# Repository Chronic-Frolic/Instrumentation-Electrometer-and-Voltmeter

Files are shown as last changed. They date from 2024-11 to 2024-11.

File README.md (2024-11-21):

# Instrumentation Electrometer and Voltmeter
Instrumentation Electrometer and Voltmeter for Proyecto Avanzado I, Engineering Physics undergraduate course, EAFIT University.

## Referencias
[1] PHYWE Systeme GmbH & Co. KG, Universal Measuring Amplifier: Operating Instructions, Göttingen, Alemania. [En línea]. Disponible en: www.phywe.com. Acceso: 20 de noviembre de 2024.

[2] PHYWE Systeme GmbH & Co. KG, Photocell with Housing: Operating Instructions, Göttingen, Alemania. [En línea]. Disponible en: www.phywe.com. Acceso: 20 de noviembre de 2024.

[3] PHYWE Systeme GmbH & Co. KG, Dielectric Constant of Different Materials: Operating Instructions, Göttingen, Alemania. [En línea]. Disponible en: www.phywe.com. Acceso: 20 de noviembre de 2024.

[4] PHYWE Systeme GmbH & Co. KG, Diffraction through a Slit and Heisenberg’s Uncertainty Principle: Operating Instructions, Göttingen, Alemania. [En línea]. Disponible en: www.phywe.com. Acceso: 20 de noviembre de 2024.

[5] PHYWE Systeme GmbH & Co. KG, Planck’s “Quantum of Action” from the Photoelectric Effect: Laboratory Experiment, Göttingen, Alemania. [En línea]. Disponible en: www.phywe.com. Acceso: 20 de noviembre de 2024.

[6] Microchip Technology Inc., MCP6001/1R/1U/2/4 - 1 MHz, Low-Power Op Amp: Datasheet, documento DS20001733L, versión actualizada 2020. [En línea]. Disponible en: www.microchip.com. Acceso: 20 de noviembre de 2024.

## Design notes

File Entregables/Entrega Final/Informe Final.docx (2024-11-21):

# Desarrollo de Voltímetro de Instrumentación y Electrómetro de Instrumentación para su Uso en Laboratorios de Física

S. Jiménez* y C. A. Trujillo†

Escuela de Ciencias Aplicadas e Ingeniería, Universidad EAFIT.

Carrera 49 #7 sur 50, Medellín, Colombia.

*sjimenezh1@eafit.edu.co

†catrujilla@eafit.edu.co

# Resumen

Se presenta el desarrollo de un voltímetro y un electrómetro de instrumentación, diseñados como alternativas económicas al amplificador universal de PHYWE para laboratorios de física. El voltímetro fue probado con éxito en experimentos para confirmar el Principio de Incertidumbre de Heisenberg, mientras que el electrómetro, en su etapa final de diseño, está optimizado para determinar la constante de Planck y constantes dieléctricas. Ambos instrumentos destacan por su modularidad, reparabilidad y adecuación educativa. Este documento describe el proceso iterativo de desarrollo, la validación experimental y la comparación con el amplificador de PHYWE, resaltando las mejoras introducidas.

Palabras Clave: Metrología, Electromagnetismo, Física Moderna, Principio de Incertidumbre de Heisenberg, Constante de Planck, Constante Dieléctrica, Voltímetro, Electrómetro.

# Abstract

We present the development of an instrumentation voltmeter and electrometer designed as cost-effective alternatives to the PHYWE universal measuring amplifier for use in physics laboratories. The voltmeter was successfully tested in experiments confirming Heisenberg's Uncertainty Principle, while the electrometer, in its final design stage, is optimized for determining Planck's constant and dielectric constants. Both instruments prioritize modularity, repairability, and educational suitability. This document details the iterative development process, experimental validation, and comparison with the PHYWE amplifier, emphasizing the improvements introduced by these instruments.

Keywords: Metrology, Electromagnetism, Modern Physics, Heisenberg's Uncertainty Principle, Planck's Constant, Dielectric Constant, Voltmeter, Electrometer.

# Introducción

El desarrollo de instrumentos de medición asequibles y funcionales es crucial para mejorar la experiencia educativa en laboratorios de física. Este proyecto aborda las limitaciones del amplificador universal de medición PHYWE, cuyo alto costo, configuración compleja y falta de una pantalla integrada dificultan su uso en entornos académicos. Se diseñaron y construyeron un voltímetro y un electrómetro de instrumentación, enfocados en la simplicidad de uso, reparabilidad y costo reducido, optimizando su integración en experimentos como la confirmación del Principio de Incertidumbre de Heisenberg, la determinación de la constante de Planck y determinación de constantes dieléctricas.

El diseño se centró en instrumentos compactos y específicos para cada experimento, eliminando configuraciones previas y mejorando la ergonomía en el laboratorio. Estos dispositivos buscan no solo igualar las capacidades del equipo comercial, sino también ofrecer una alternativa sostenible y adaptable a largo plazo.

Este artículo detalla la metodología de diseño y fabricación de los instrumentos, presenta los resultados obtenidos y discute las mejoras proyectadas para maximizar su desempeño en aplicaciones futuras.

# Metodología

El desarrollo del voltímetro y electrómetro de instrumentación se llevó a cabo mediante un enfoque iterativo dividido en etapas claras: diseño electrónico, diseño y fabricación de la carcasa, ensamblaje de componentes y pruebas funcionales. Este proceso permitió realizar cuatro prototipos para el voltímetro y dos para el electrómetro, asegurando un diseño optimizado y funcional para ambos instrumentos. Estas herramientas, diseñadas para experimentos de física moderna y electromagnetismo, se enfocaron en la precisión, modularidad y reparabilidad.

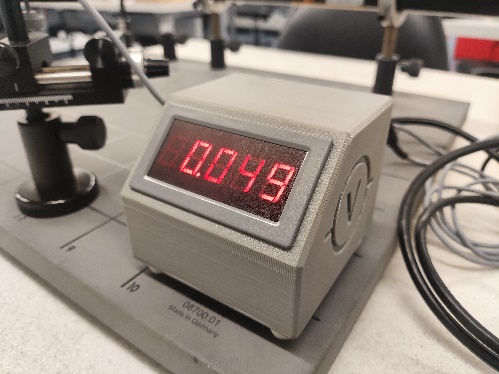
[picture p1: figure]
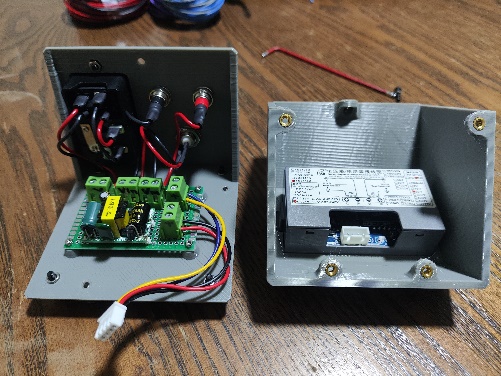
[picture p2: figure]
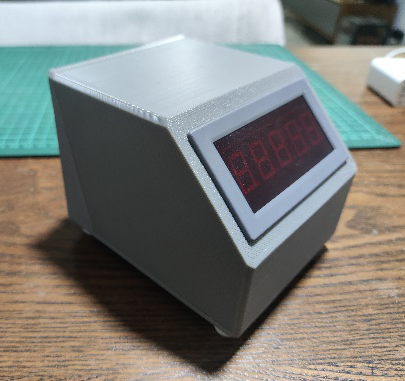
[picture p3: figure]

(a) (b) (c)

Figura 2: Diferentes iteraciones del voltímetro (a) Segundo prototipo (b) Tercer prototipo (detalle interno) (c) Cuarto prototipo

## Diseño Electrónico

Ambos instrumentos comparten componentes clave, incluidos el módulo voltímetro-pantalla YB5145B, el conector C13 con fusible y switch, y bloques terminales que refuerzan la modularidad. El módulo voltímetro-pantalla fue elegido por su precisión de ±1 mV, su retroiluminación roja y sus dígitos grandes, ideales para condiciones de baja iluminación, como las requeridas en los experimentos de física moderna.

El circuito del electrómetro utiliza un amplificador operacional MCP6001 en configuración de buffer de ganancia unitaria, seleccionado por su corriente de polarización de entrada extremadamente baja (1 pA), lo que permite que la resistencia general del circuito sea determinada por la alta resistencia entre los pines del circuito. Para mejorar su resistencia frente a errores operativos, el diseño final incluye un resistor de protección que limita la corriente de salida en condición de polarización inversa, aunque no se implementó protección contra sobrevoltaje debido a las corrientes de fuga asociadas a los diodos necesarios, que podrían comprometer las mediciones de alta precisión asociadas a cargas capacitivas.

Durante el desarrollo, el electrómetro experimentó un fallo crítico causado por un corto en la fuente de alimentación de 5 V, lo que dañó el amplificador operacional. Este problema será corregido en la versión final mediante el uso de un socket para facilitar el reemplazo del MCP6001 y garantizar la reparabilidad a largo plazo.

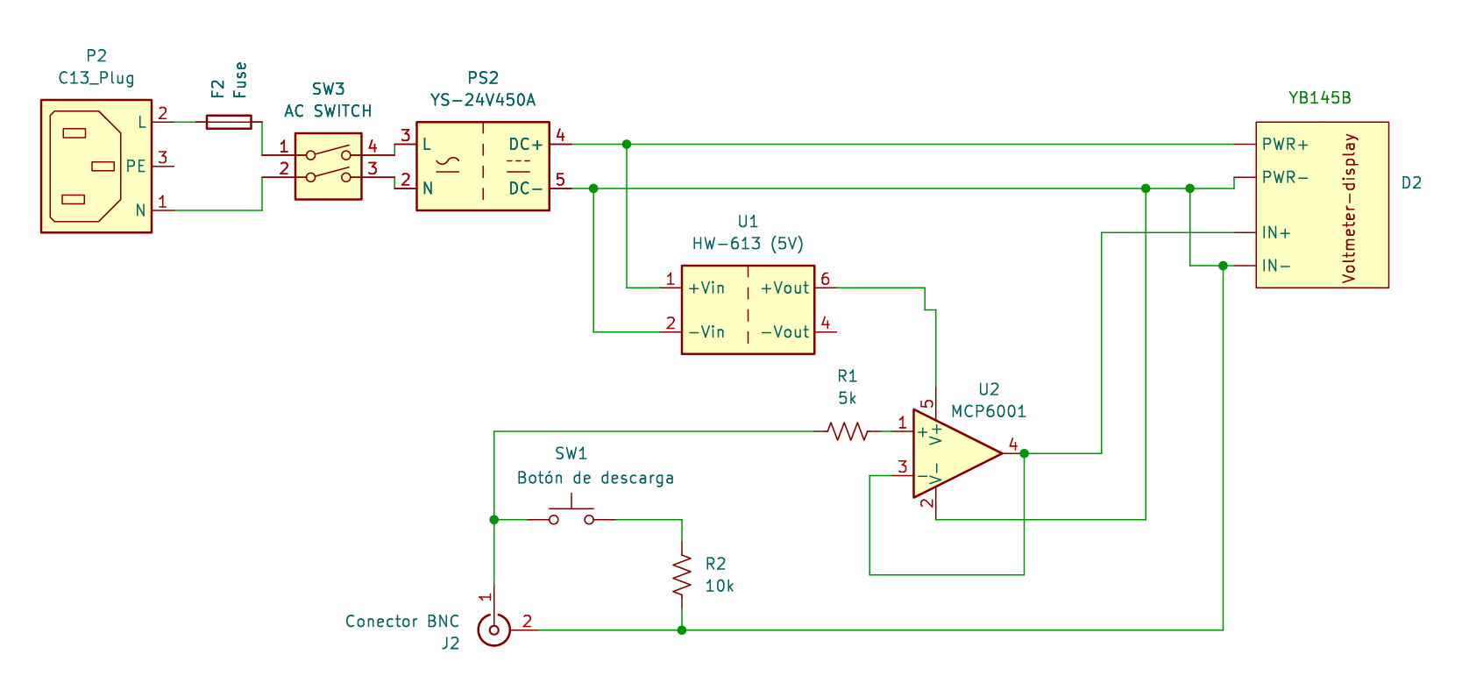
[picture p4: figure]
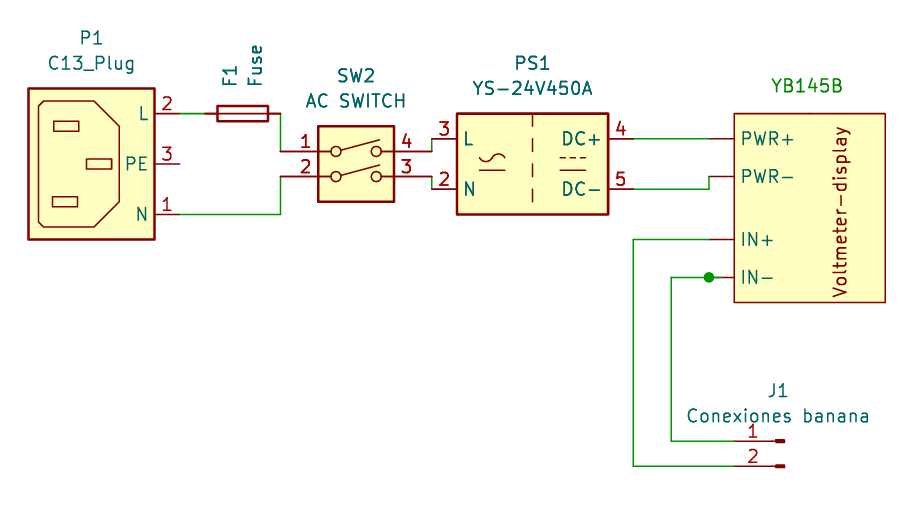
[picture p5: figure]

(a) (b)

Figura 1: Diagramas de conexiónes finales (a) Electrómetro (b) Voltímetro

## Diseño y Fabricación de la Carcasa

Las carcasas de ambos instrumentos se diseñaron en Autodesk Fusion 360 y se fabricaron en PETG utilizando impresión 3D con una Creality CR-10 modificada. El diseño priorizó la modularidad, y la facilidad de fabricación y mantenimiento, incorporando insertos roscados para permitir un desmontaje sencillo y ajustes futuros. Las carcasas comparten dimensiones compactas y presentan una inclinación de 45° en la pantalla, mejorando la ergonomía.

## Pruebas y Validación

La validación de los instrumentos se realizó integrándolos en los montajes experimentales correspondientes a dos aplicaciones clave: la confirmación del Principio de Incertidumbre de Heisenberg y la determinación de la constante de Planck.

En el primer experimento, un láser He-Ne fue dirigido hacia una rendija simple, generando un patrón de difracción. Una fotocélula, montada en un tornillo micrométrico, capturó la luz difractada. El voltímetro midió el voltaje de salida de la fotocélula en posiciones específicas, permitiendo identificar el máximo central y el primer mínimo, necesarios para calcular los ángulos de difracción.

Para el segundo experimento, una lámpara de vapor de mercurio proporcionó un espectro de emisión que fue separado en longitudes de onda específicas mediante una rejilla de difracción de 600 líneas/mm. Estas longitudes de onda incidieron sobre una fotocélula de vacío, generando un voltaje proporcional a la frecuencia de la luz incidente. El electrómetro midió este voltaje en condiciones de alta impedancia, garantizando que las características del circuito no afectaran las mediciones.

Ambos montajes aseguraron un entorno experimental adecuado para evaluar el desempeño de los instrumentos en contextos de física moderna, proporcionando las bases necesarias para los análisis posteriores.

## Enfoque en Modularidad y Reparabilidad

El diseño iterativo enfatizó la modularidad y reparabilidad como principios fundamentales. Los bloques terminales y el uso compartido del módulo voltímetro-pantalla simplifican el ensamblaje y permiten futuras reparaciones o ajustes según las necesidades. Este enfoque garantiza la sostenibilidad y adaptabilidad de los instrumentos, asegurando su utilidad a largo plazo en entornos de laboratorio.

_______________________

Este enfoque metodológico permitió la construcción de instrumentos específicos, precisos y funcionales, sentando las bases para los resultados experimentales que se presentan en la siguiente sección.

# Resultados

## Voltímetro

El voltímetro se utilizó en el experimento para confirmar el Principio de Incertidumbre de Heisenberg, midiendo los voltajes generados por una fotocélula en puntos clave del patrón de difracción. Los datos registrados permitieron calcular una relación de 2.0038, con el valor esperado siendo 1. Esta discrepancia se atribuye a un error en la ecuación proporcionada en la guía de laboratorio, no al desempeño del instrumento.

El voltímetro mostró una precisión de ±1 mV, equivalente al modo de baja deriva del amplificador PHYWE. Su integración directa en el montaje experimental simplificó la configuración, haciendo posible realizar las mediciones necesarias de forma compacta y eficiente.

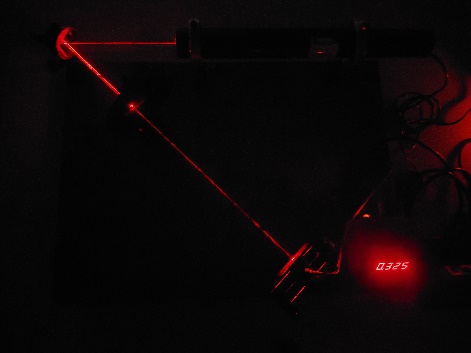
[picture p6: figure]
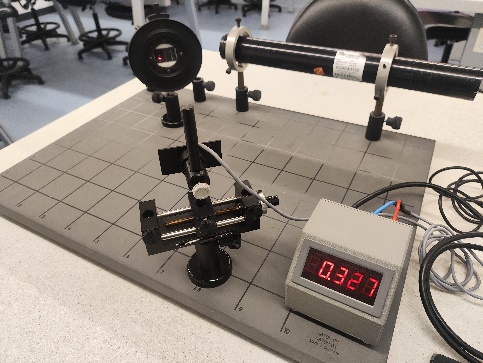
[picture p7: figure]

(a) (b)

Figura 3. Voltímetro (a) Desempeño en las condiciones experimentales (b) Integración al laboratorio

## Electrómetro

El electrómetro, aún en fase de ajustes finales, está diseñado para experimentos de determinación de la constante de Planck y medición de constantes dieléctricas. Su configuración incluye un rango de entrada de 0-5 V, adecuado para los voltajes esperados en estos experimentos, típicamente entre 0 y 2 V. La alta resistencia de entrada (10^12 Ω) asegura mediciones precisas minimizando pérdidas de carga, cumpliendo con los requisitos de los montajes experimentales.

El diseño inicial presentó un fallo crítico causado por un corto circuito en la fuente de alimentación de 5 V, lo que dañó el amplificador MCP6001. Este problema fue resuelto en el diseño final, que incorpora un socket para facilitar el reemplazo del amplificador y un resistor de protección que limita la corriente en caso de uso indebido. Estas mejoras refuerzan la durabilidad y la capacidad de reparación del electrómetro.

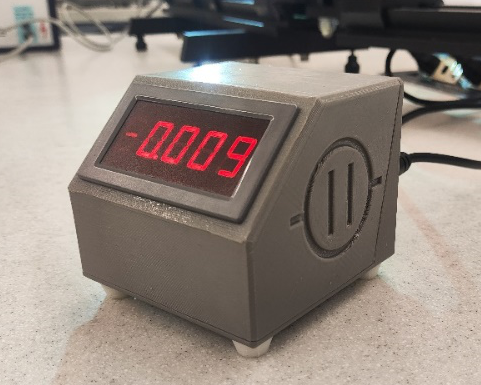
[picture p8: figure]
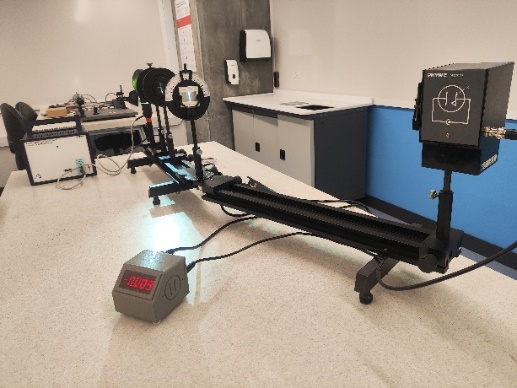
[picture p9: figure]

(a) (b)

Figura 4: Electrómetro (a) Detalle del primer prototipo (b) Integración con el experimento de determinación de la constante de Planck

## Comparación Cuantitativa con el Amplificador PHYWE

Característica | Voltímetro/Electrómetro | Amplificador PHYWE
Resolución (Voltímetro) | ±1 mV | ±1 mV
Resolución (Electrómetro) | ±1 mV | ±10 mV
Resistencia de entrada (Electrómetro) | 10^12 Ω | 10^13 Ω
Rango de voltaje (Electrómetro) | 0-5 V | ±10 V

Tabla 1: Comparativa cualitativa entre instrumentos desarrollados y el Amplificador Universal de Medida de PHYWE

Ambos instrumentos cumplen con los requisitos de los experimentos y presentan ventajas clave en términos de precisión y adaptabilidad. El voltímetro mostró un desempeño comparable al del amplificador PHYWE en el modo de baja deriva, mientras que el electrómetro, una vez finalizado, ofrecerá mayor flexibilidad y facilidad de uso en experimentos de alta impedancia.

# Conclusiones

El desarrollo del voltímetro y electrómetro de instrumentación representa un avance significativo en la implementación de herramientas asequibles, reparables y funcionales para laboratorios de física. Estos instrumentos no solo igualan, sino que en varios aspectos superan las capacidades del amplificador universal PHYWE, ofreciendo una solución práctica y sostenible para los experimentos de física moderna y electromagnetismo.

El voltímetro fue validado con éxito en el experimento del Principio de Incertidumbre de Heisenberg, demostrando un rendimiento equivalente al equipo comercial en precisión y superándolo en ergonomía y facilidad de uso. Su diseño compacto, pantalla integrada y capacidad para operar de manera autónoma mejoraron la experiencia experimental y optimizaron el espacio en el laboratorio.

Aunque el electrómetro no estuvo completamente funcional durante la etapa inicial, su diseño ha sido verificado como sólido y se están implementando ajustes finales. Una vez completadas estas modificaciones, permitirá realizar experimentos como la determinación de la constante de Planck y la medición de constantes dieléctricas con mayor precisión y confiabilidad que el equipo comercial, cuyo modo electrómetro está actualmente inoperativo.

Más allá de los logros técnicos, este proyecto tiene un impacto significativo en el contexto educativo. Los instrumentos desarrollados reducen los costos de equipamiento, democratizan el acceso a herramientas avanzadas y enriquecen la experiencia práctica de los estudiantes al ofrecer dispositivos diseñados para su facilidad de uso y sostenibilidad. Este enfoque no solo mejora la formación académica, sino que también sienta un precedente para futuros desarrollos en tecnología educativa.

El proyecto concluye con una base sólida para la implementación de estos instrumentos en los laboratorios de Ingeniería Física, marcando un paso hacia la modernización y optimización de las prácticas experimentales. Las pruebas finales del electrómetro están programadas para completarse con el experimento de determinación de h, lo que consolidará su utilidad en aplicaciones clave.

# Agradecimientos

Agradezco profundamente a Carlos Alejandro Trujillo por su invaluable guía a lo largo del desarrollo de este proyecto, brindando orientación clave en cada etapa. También extiendo mi gratitud a Álvaro Andrés Velásquez por su aporte en la verificación del circuito del electrómetro, cuya experiencia en electrónica analógica fue fundamental para garantizar la solidez técnica del electrómetro. Asimismo, agradezco al Centro de Laboratorios (CLAB) de la Universidad EAFIT por su apoyo financiero, que permitió la adquisición de los materiales y componentes necesarios para la construcción de los instrumentos.

# Referencias

[1] PHYWE Systeme GmbH & Co. KG, Universal Measuring Amplifier: Operating Instructions, Göttingen, Alemania. [En línea]. Disponible en: www.phywe.com. Acceso: 20 de noviembre de 2024.

[2] PHYWE Systeme GmbH & Co. KG, Photocell with Housing: Operating Instructions, Göttingen, Alemania. [En línea]. Disponible en: www.phywe.com. Acceso: 20 de noviembre de 2024.

[3] PHYWE Systeme GmbH & Co. KG, Dielectric Constant of Different Materials: Operating Instructions, Göttingen, Alemania. [En línea]. Disponible en: www.phywe.com. Acceso: 20 de noviembre de 2024.

[4] PHYWE Systeme GmbH & Co. KG, Diffraction through a Slit and Heisenberg’s Uncertainty Principle: Operating Instructions, Göttingen, Alemania. [En línea]. Disponible en: www.phywe.com. Acceso: 20 de noviembre de 2024.

[5] PHYWE Systeme GmbH & Co. KG, Planck’s “Quantum of Action” from the Photoelectric Effect: Laboratory Experiment, Göttingen, Alemania. [En línea]. Disponible en: www.phywe.com. Acceso: 20 de noviembre de 2024.

[6] Microchip Technology Inc., MCP6001/1R/1U/2/4 - 1 MHz, Low-Power Op Amp: Datasheet, documento DS20001733L, versión actualizada 2020. [En línea]. Disponible en: www.microchip.com. Acceso: 20 de noviembre de 2024.

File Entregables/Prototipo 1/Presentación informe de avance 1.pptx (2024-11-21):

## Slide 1

## Primer informe de avance

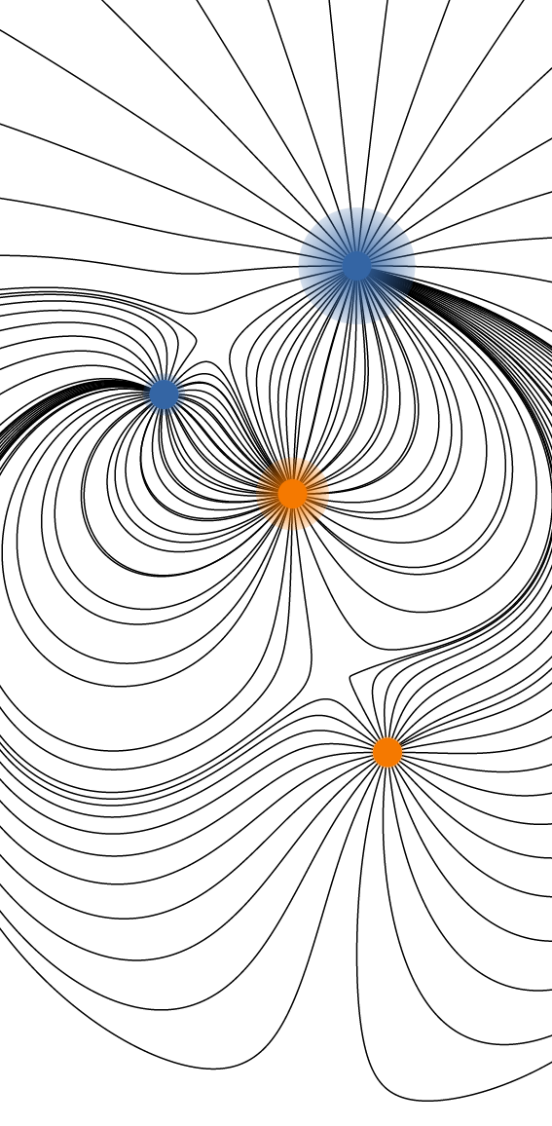
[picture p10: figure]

- Desarrollo de medidor de voltaje de instrumentación para su uso en laboratorios de física

## Índice

- Resultados

Avance del cronograma

Estrategias de mitigación

Conclusiones

Bibliografía

## Resultados

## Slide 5

Revisión teórica

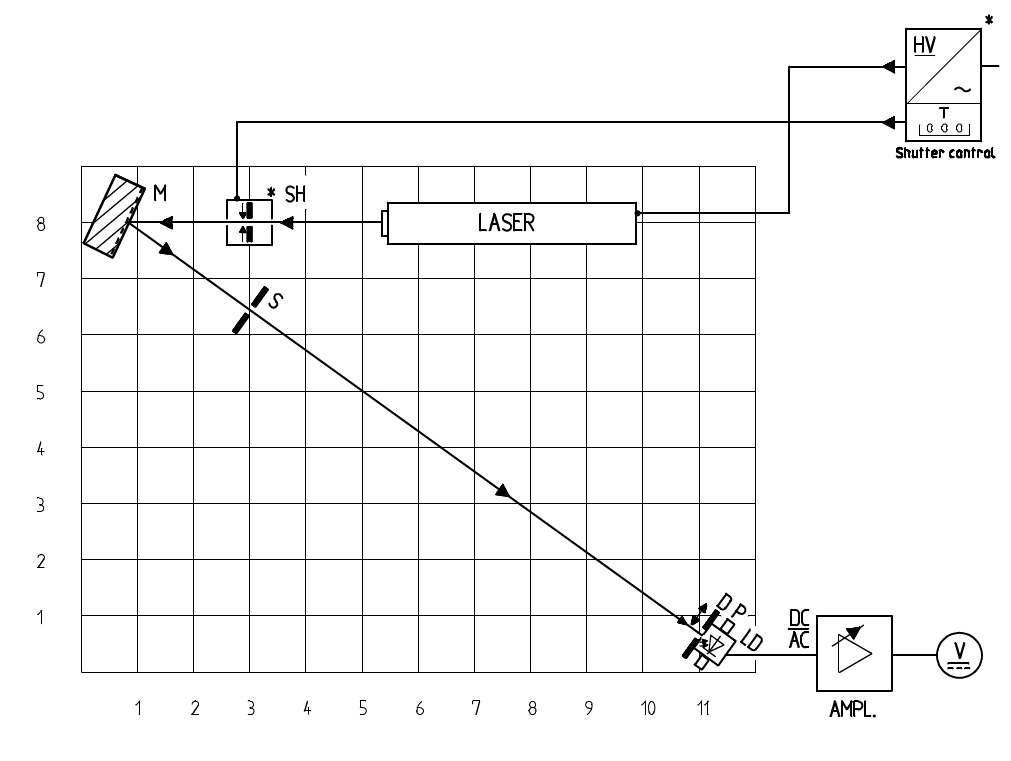
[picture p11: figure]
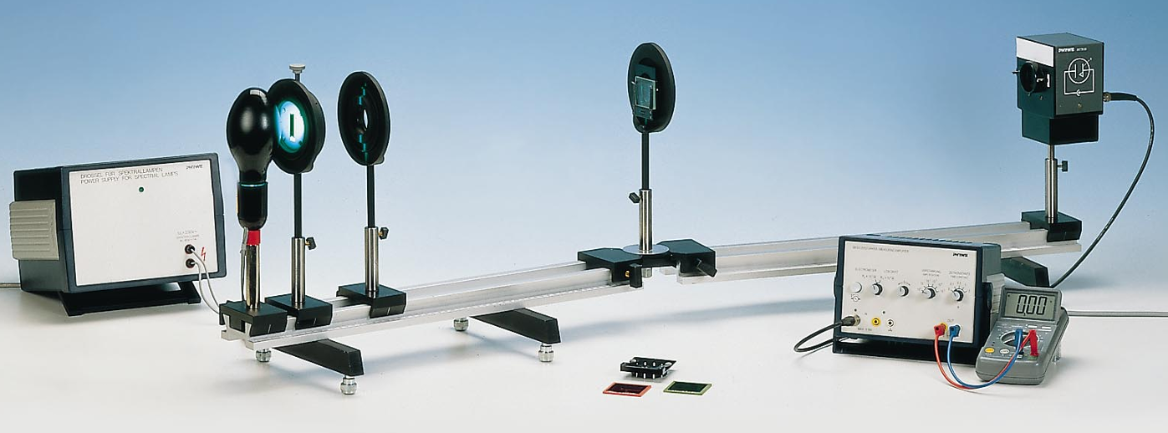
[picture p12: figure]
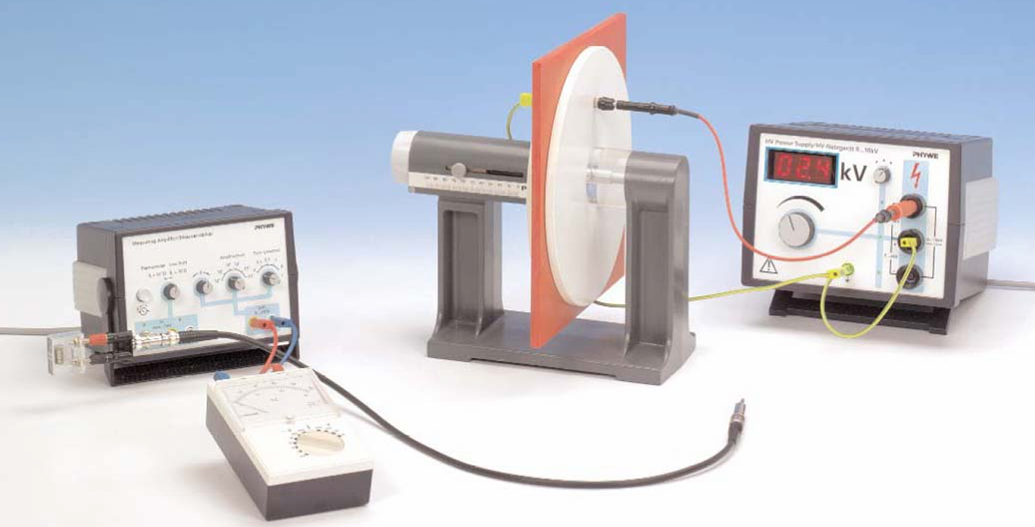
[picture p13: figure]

Tomado de [2]

Tomado de [1]

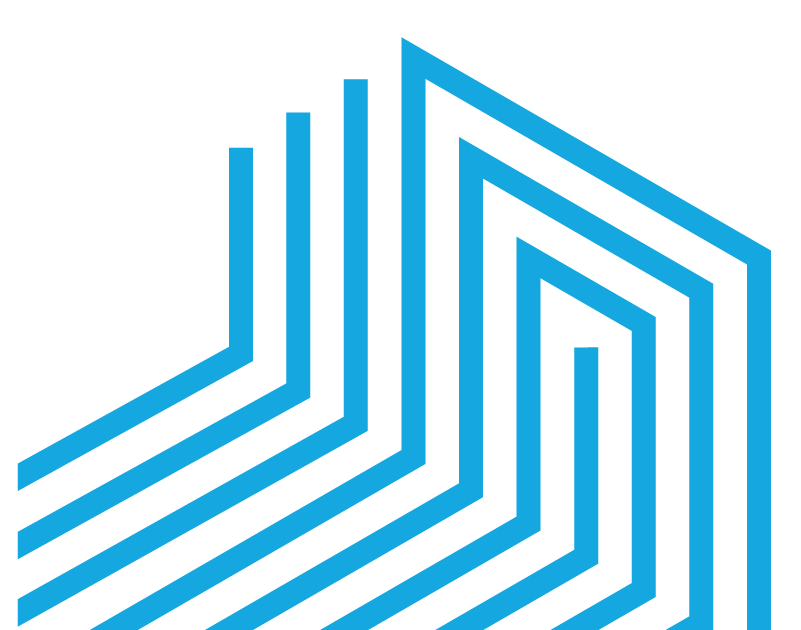
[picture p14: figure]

Tomado de [3]

## Prototipo 1

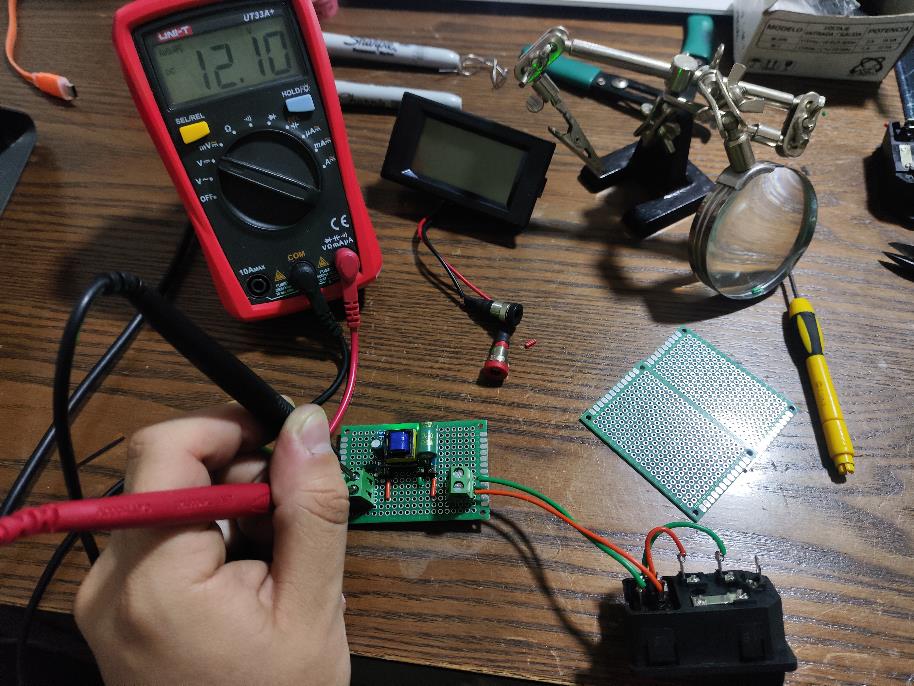
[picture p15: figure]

Elaboración propia

- Caracterización de la fuente de poder

## Prototipo 1

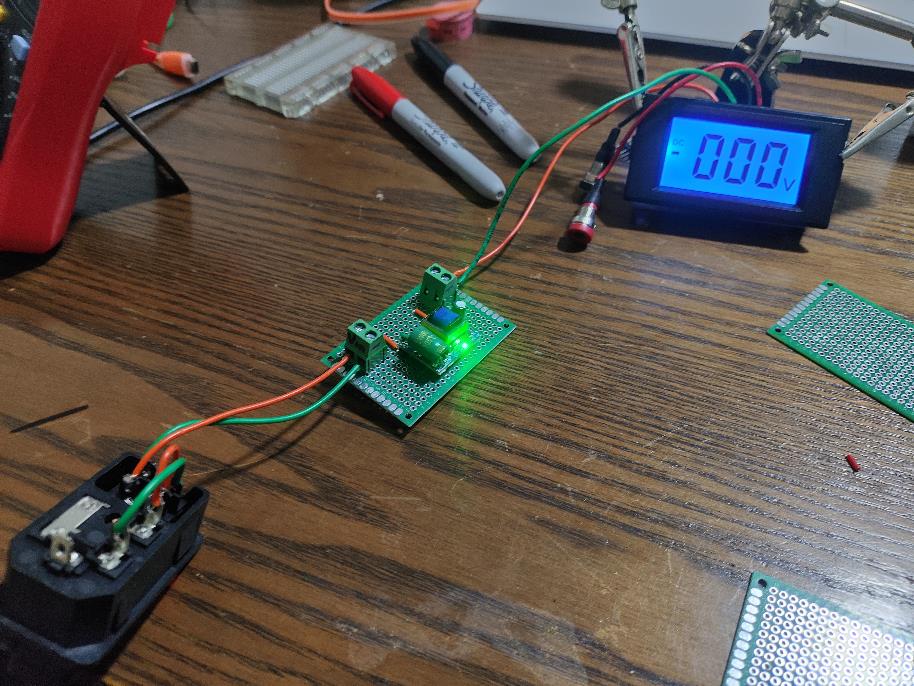
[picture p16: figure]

Elaboración propia

- Verificación del circuito final

## Prototipo 1

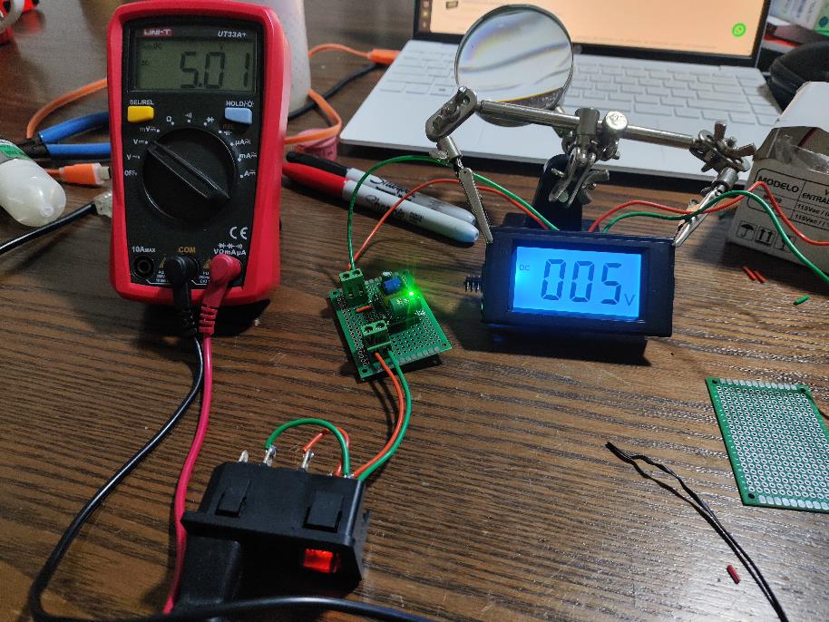
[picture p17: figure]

Elaboración propia

- Precisión y exactitud de la medida

## Prototipo 1

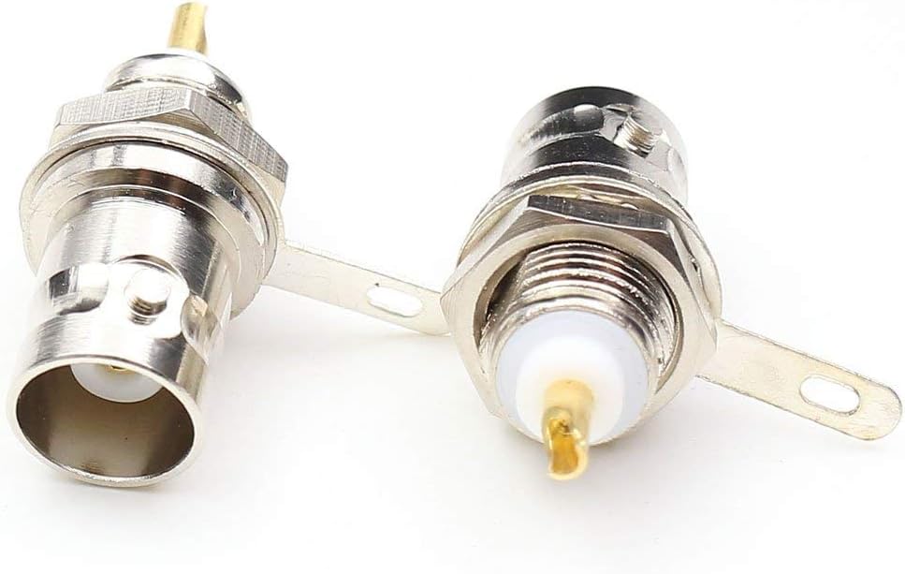
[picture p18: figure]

Tomado de [4]

- Consecusión de partes fundamentales

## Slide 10

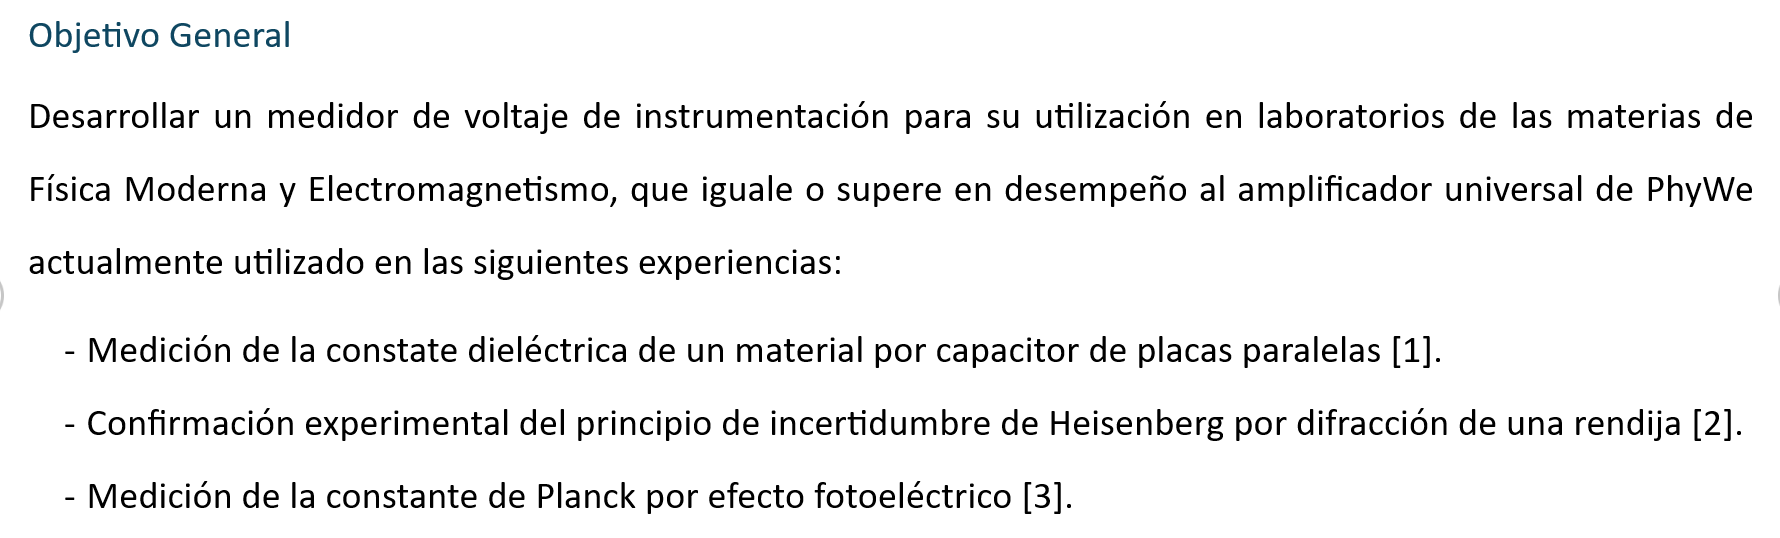
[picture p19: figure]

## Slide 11

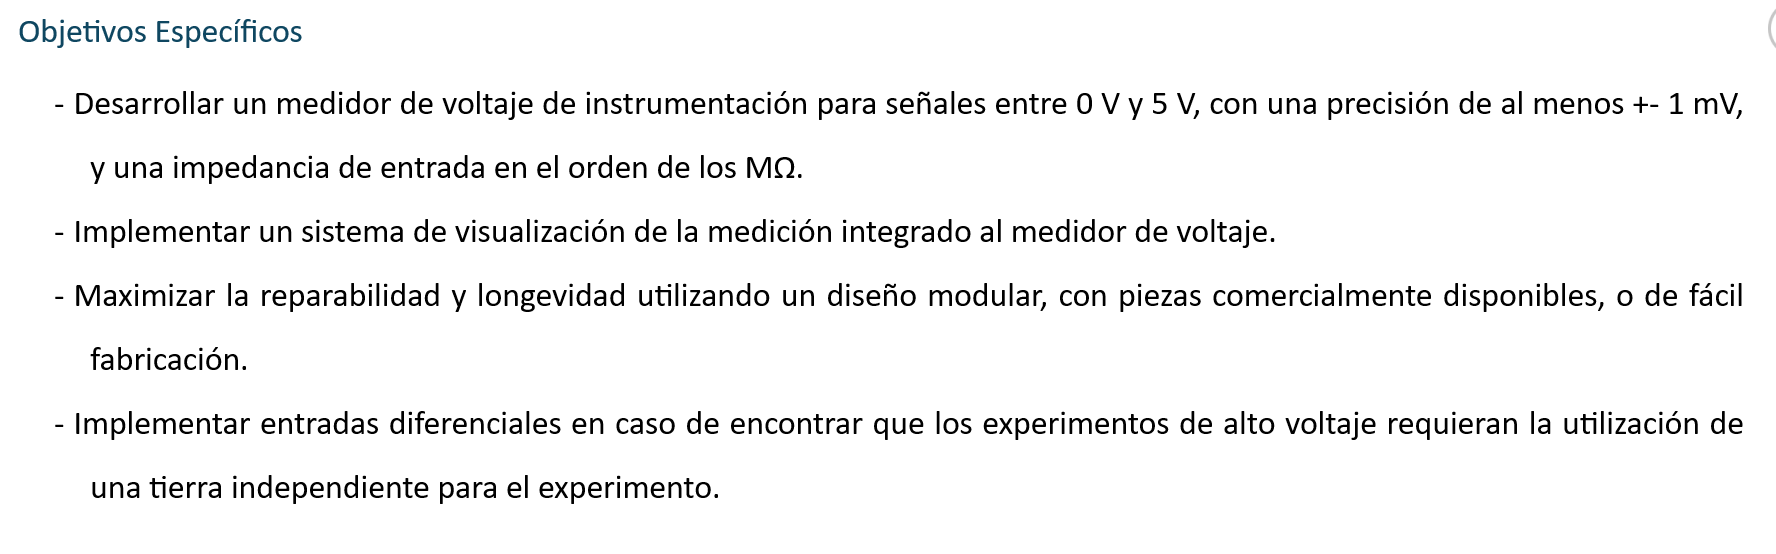
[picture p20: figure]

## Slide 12

Avance del cronograma

Etapa | Diseño electrónico | Diseño Carcasa | Elaboración electrónica | Elaboración carcasa | Pruebas de funcionamiento
Fundamentación (Definición del proyecto e investigación inicial) | Semanas 2 – 4
Prototipo 1 | Semana 5 | Semana 6 | Semana 7 | Semana 7 | Semana 8
Prototipo 2 | Semana 8 | Semana 9 | Semana 9 | Semana 10 | Semana 10
Medidor final | Semana 10 | Semana 11 | Semana 12 | Semana 13 | Semana 13
Documentación y reporte de resultados | Semanas 14 - 16

## Mitigación

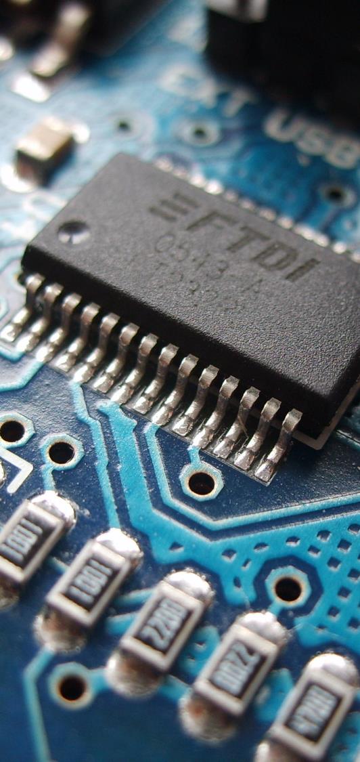
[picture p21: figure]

- Se implementarán las siguientes estrategias:

- Distribuidores: Amazon y Aliexpress

- Se fabricará un cable BNC a conector banana para hacer compatible el prototipo 1

- Se usará el prototipo 1 para hacer pruebas de funcionamiento

- Importación de partes fundamentales

- Estrategias de

- Adaptación de experimentos

- Pruebas preeliminares

## Partes en importación

Tomado de [4]

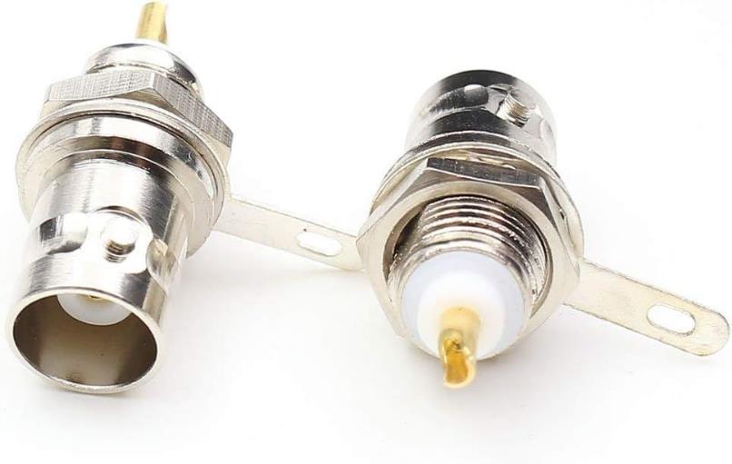
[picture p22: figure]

- Conectores BNC compatibles con equipos PHYWE

## Partes en importación

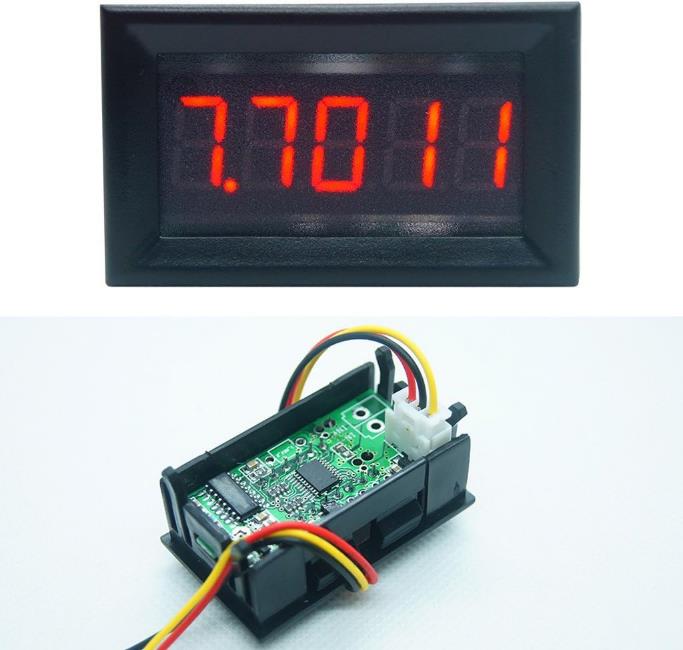
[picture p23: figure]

- Opción 1: Módulo voltímetro de alta precision con funcionalidad tare

Tomado de [5]

## Partes en importación

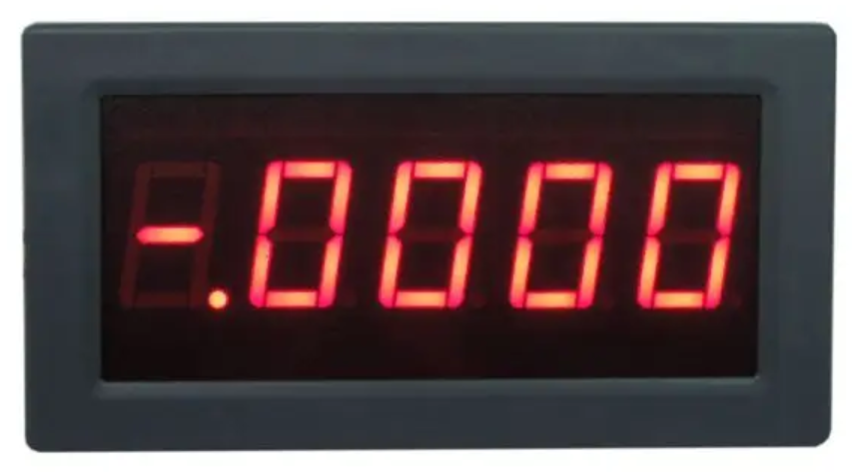
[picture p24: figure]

- Opción 2: Módulo voltímetro de aislamiento de alta precision

Tomado de [6]

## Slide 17

Conclusiones

## Bibliografía

[1] PHYWE Systeme GmbH & Co., "Dielectric constant of different materials," Göttingen.
[2] PHYWE Systeme GmbH & Co., "Diffraction through a slit and Heisenberg's uncertainty principle," Göttingen.
[3] PHYWE Systeme GmbH & Co., "Plank's "quantum of action" from the photoelectric effect (line separation by difraction),“ Göttingen.
[4] Amazon.com, "BNC Chassis Panel Mount Socket Female Jack Solder Type Connectors Adapter 6-Pack," [Online]. Available: https://www.amazon.com/gp/product/B07FB39S1L/ref=ox_sc_act_title_3?smid=A10PG8DP5LW0Q1&psc=1. [Accessed 2024]
[5] Amazon.com, "Digital Voltmeter DC Voltage Display 0-33.000V (0-33V) 5-Digits Bit High Precision Voltage Meter," [Online]. [Accessed 2024].
[6] Aliexpress.com, "YB5145BI DC Isolation Voltmeter 4 1/2 LED Digital Voltage Meter 5 Bits," [Online]. [Accessed 2024].

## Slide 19

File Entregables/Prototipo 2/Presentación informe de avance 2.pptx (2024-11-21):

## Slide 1

## Primer informe de avance


- Desarrollo de medidor de voltaje de instrumentación para su uso en laboratorios de física
- Estudiante: Sebastián Jiménez Henao
- Tutor: Carlos Alejandro Trujillo Anaya
- 25-10-2025

## Índice

- Resultados

Avance del cronograma

Conclusiones

Bibliografía

## Resultados

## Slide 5

Revisión teórica


Tomado de [1]


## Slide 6

Revisión teórica


Tomado de [2]

## Prototipo 2


Elaboración propia

- Modelado de carcasa impresa


## Prototipo 2


Elaboración propia

- Verificación de funcionamiento

## Prototipo 3


Elaboración propia

- Miniaturización y refinamiento final

## Prototipo 3


Elaboración propia

- Miniaturización y refinamiento final

## Prototipo 3


Elaboración propia

- Verificación de funcionamiento

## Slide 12

Objetivo general

Desarrollar un medidor de voltaje de instrumentación comparable en desempeño al amplificador universal Phywe actualmente en uso en las siguientes experiencias de Ingeniería Física de la Universidad EAFIT:
- Confirmación experimental del principio de incertidumbre de Heisenberg por difracción de una rendija [1].
- Medición de la constante de Planck por efecto fotoeléctrico [2].

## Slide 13

Objetivos específicos

- Desarrollar un medidor de voltaje de instrumentación para señales entre 0 V y 5 V, con una precisión de al menos +- 1 mV, y una impedancia de entrada en el orden de los MΩ.
- Implementar un sistema de visualización de la medición integrado al medidor de voltaje.
- Maximizar la reparabilidad y longevidad utilizando un diseño modular, con piezas comercialmente disponibles, o de fácil fabricación.

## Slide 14

Avance del cronograma

Etapa\Semana | 1 | 2 | 3 | 4 | 5 | 6 | 7 | 8 | 9 | 10 | 11 | 12 | 13 | 14 | 15 | 16
Fundamentación
Prototipo 1
Prototipo 2
Medidor final
Documentación y reporte de resultados

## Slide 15

Conclusiones

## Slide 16

Conclusiones

- Se cumplieron los objetivos específicos, logrando un medidor de voltaje pequeño, funcional y reparable.
- Quedan restando las pruebas de funcionamiento, pendiente de coordinación con el CLAB para las mismas.
- Se cumple la pregunta de investigación, demostrando la creación de un medidor de voltaje apto las experiencias previamente mencionadas de la materia de Física Moderna de la carrera de Ingeniería Física

## Bibliografía

[1] PHYWE Systeme GmbH & Co., "Diffraction through a slit and Heisenberg's uncertainty principle," Göttingen.
[2] PHYWE Systeme GmbH & Co., "Plank's "quantum of action" from the photoelectric effect (line separation by difraction),“ Göttingen.
[3] Amazon.com, "BNC Chassis Panel Mount Socket Female Jack Solder Type Connectors Adapter 6-Pack," [Online]. Available: https://www.amazon.com/gp/product/B07FB39S1L/ref=ox_sc_act_title_3?smid=A10PG8DP5LW0Q1&psc=1. [Accessed 2024]
[4] Amazon.com, "Digital Voltmeter DC Voltage Display 0-33.000V (0-33V) 5-Digits Bit High Precision Voltage Meter," [Online]. [Accessed 2024].
[5] Aliexpress.com, "YB5145BI DC Isolation Voltmeter 4 1/2 LED Digital Voltage Meter 5 Bits," [Online]. [Accessed 2024].

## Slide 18

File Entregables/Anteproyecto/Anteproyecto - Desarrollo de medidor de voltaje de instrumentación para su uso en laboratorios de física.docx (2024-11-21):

# Desarrollo de medidor de voltaje de instrumentación para su uso en laboratorios de física

Estudiante:

Sebastián Jiménez Henao (sjimenezh1@eafit.edu)

Tutor del proyecto:

Carlos Alejandro Trujillo Anaya (catrujilla@eafit.edu.co)

Profesora del curso:

Elena Montilla Rosero (emontill@eafit.edu.co)

Universidad EAFIT

Escuela de Ciencias Aplicadas e Ingeniería

Pregrado de Ingeniería Física

Proyecto Avanzado I

# Tabla de Contenido

# Tabla de Tablas

# Planteamiento del proyecto

En el ámbito de la enseñanza de los principios físicos que debe dominar un ingeniero físico, la experimentación de primera mano es extremadamente valiosa. Con esto en mente, la precisión, versatilidad y facilidad de uso de los instrumentos de medición juegan un papel crucial en la formación práctica de los estudiantes. Particularmente, en experimentos fundamentales como la determinación de la constante dieléctrica mediante capacitores de placas planas, el estudio del efecto fotoeléctrico, y la exploración del principio de incertidumbre de Heisenberg a través de la difracción de rendija, se requiere la medición precisa de voltajes DC con características específicas de amplificación, robustez ante el ruido, y resistencia de entrada.

Los amplificadores universales actualmente disponibles en el mercado, si bien cumplen con los requisitos técnicos, presentan dos limitaciones significativas: su alto costo, que restringe la cantidad de unidades que una institución educativa puede adquirir y poner en uso concurrente, y la necesidad de utilizar un voltímetro externo, lo que complica el proceso de medición y aumenta la probabilidad de errores experimentales.

Ante esta problemática, surge la necesidad de desarrollar un medidor de voltaje de instrumentación específicamente diseñado para entornos educativos de ingeniería física. Este dispositivo debe no solo cumplir con los requerimientos técnicos de amplificación unitaria y alta resistencia de entrada, sino también incorporar características que faciliten su uso en un contexto pedagógico.

La pregunta de investigación que guía este desarrollo será: ¿Cómo se puede diseñar y construir un medidor de voltaje de instrumentación que combine precisión en la medición de voltajes DC, facilidad de uso, modularidad, y costo accesible para su implementación en laboratorios pedagógicos de ingeniería física?

Este desafío requiere la aplicación integrada de conocimientos en electrónica, diseño de circuitos, instrumentación y metrología. Los estudiantes de ingeniería física, con su formación interdisciplinaria que abarca tanto los fundamentos físicos como los principios de la ingeniería electrónica, están en una posición única para abordar este problema. El desarrollo de este medidor de voltaje no solo resolvería una necesidad práctica en los laboratorios universitarios, sino que también proporcionaría una valiosa experiencia de aprendizaje en el diseño y construcción de instrumentación científica. Específicamente, el estudiante a cargo del desarrollo de este proyecto tiene experiencia extracurricular con el diseño y fabricación de impresoras 3D, implementación de circuitos de potencia media y metrología con microcontroladores, áreas que presentan alta aplicabilidad al problema a resolver.

# Objetivos del Proyecto

En esta sección se precisarán los objetivos y especificaciones de ingeniería requeridas para resolver el problema previamente planteado.

## Objetivo General

Desarrollar un medidor de voltaje de instrumentación para su utilización en laboratorios de las materias de Física Moderna y Electromagnetismo, que iguale o supere en desempeño al amplificador universal de PhyWe actualmente utilizado en las siguientes experiencias:

- Medición de la constate dieléctrica de un material por capacitor de placas paralelas [1].
- Confirmación experimental del principio de incertidumbre de Heisenberg por difracción de una rendija [2].
- Medición de la constante de Planck por efecto fotoeléctrico [3].

## Objetivos Específicos

- Desarrollar un medidor de voltaje de instrumentación para señales entre 0 V y 5 V, con una precisión de al menos +- 1 mV, y una impedancia de entrada en el orden de los MΩ.
- Implementar un sistema de visualización de la medición integrado al medidor de voltaje.
- Maximizar la reparabilidad y longevidad utilizando un diseño modular, con piezas comercialmente disponibles, o de fácil fabricación.
- Implementar entradas diferenciales en caso de encontrar que los experimentos de alto voltaje requieran la utilización de una tierra independiente para el experimento.

# Antecedentes

El antecedente principal de este proyecto es el amplificador universal actualmente utilizado para la recolección de datos en las experiencias anteriormente detalladas [4]. Este amplificador servirá como estándar de funcionamiento mínimo en el desarrollo de este proyecto.

# Metodología Propuesta

La metodología a seguir en este proyecto estará basada en prototipos incrementales, con el objetivo de conseguir una funcionalidad básica de manera rápida e iterar sobre esta base hasta conseguir los resultados esperados del proyecto final. Cada prototipo se dividirá en 5 etapas secuenciales, 2 de diseño, 2 de fabricación y una de pruebas de funcionamiento. Se espera necesitar 2 prototipos antes de alcanzar el proyecto final.

Dentro de la etapa de pruebas de funcionamiento se espera realizar los experimentos como serían realizados por los estudiantes en el curso normal del experimento, para asegurar la paridad de funciones entre el dispositivo en pruebas y el amplificador universal de PHYWE.

Tomando como ejemplo la experiencia explorando el efecto fotoeléctrico, se realizaría el montaje experimental, logrando un espectrómetro simple, tal como es descrito en la guía [3]. Una vez se logre que la irradiancia de la lámpara de amplio espectro por mercurio de alta presión sea seccionada por una rendija regulable, colimada por su lente y difractada por la rendija de difracción, se procede a seguir el protocolo experimental descrito en [3], moviendo la fotocelda (con sus respectivos filtros para rechazar longitudes de onda del patrón de difracción de segundo orden) a las regiones de luz difractada, tomando el valor del voltaje fotoeléctrico logrado con cada longitud de onda de interés (visibles) utilizando el amplificador universal de PHYWE y un multímetro. Una vez se recolecten los datos necesarios, se calcula la constante de Planck. Luego, se reemplaza el amplificador universal por el medidor de voltaje de instrumentación, se realiza de nuevo el protocolo de toma de datos, y se calcula la constante de Planck. Se considerará en la medición del rendimiento del proyecto factores cómo la precisión del valor obtenido en relación con el valor encontrado en la literatura, facilidad de uso contra el protocolo experimental actual, y fuentes de error experimental introducidas o removidas por el protocolo experimental actualizado.

# Cronograma de Actividades

En esta sección se propone un cronograma para el desarrollo del proyecto propuesto, delimitando con una fecha límite de cada una.

Tabla 1: Cronograma del proyecto

Etapa | Diseño electrónico | Diseño Carcasa | Elaboración electrónica | Elaboración carcasa | Pruebas de funcionamiento
Fundamentación (Definición del proyecto e investigación inicial) | Semanas 2 – 4
Prototipo 1 | Semana 5 | Semana 6 | Semana 7 | Semana 7 | Semana 8
Prototipo 2 | Semana 8 | Semana 9 | Semana 9 | Semana 10 | Semana 10
Medidor final | Semana 10 | Semana 11 | Semana 12 | Semana 13 | Semana 13
Documentación y reporte de resultados | Semanas 14 - 16

# Presupuesto

En esta sección se presenta el presupuesto preliminar del proyecto, detallando cantidades, precio por unidad y encargado.

Tabla 2: Presupuesto

Ítem | Encargado | Cantidad | Precio por unidad | Subtotal
Hora consultoría: Carlos Trujillo | CLAB | 10 | $ 100,000.00 | $ 1,000,000.00
Hora consultoría: Álvaro Velásquez | CLAB | 5 | $ 100,000.00 | $ 500,000.00
Hora de trabajo: Sebastián Jiménez | CLAB | 100 | $ 50,000.00 | $ 5,000,000.00
Filamento PETG 1 kg | CLAB | 2 | $ 98,000.00 | $ 196,000.00
Set tornillería | CLAB | 3 | $ 10,000.00 | $ 30,000.00
Módulo voltímetro 7 segmentos | CLAB | 3 | $ 30,000.00 | $ 90,000.00
Fuente 12V | CLAB | 3 | $ 10,000.00 | $ 30,000.00
Op-Amp LM324 | CLAB | 5 | $ 1,600.00 | $ 8,000.00
Selector rotativo | CLAB | 3 | $ 22,000.00 | $ 66,000.00
Electrónica - varios | CLAB | 1 | $ 300,000.00 | $ 300,000.00
Conector BNC | CLAB | 5 | $ 3,000.00 | $ 15,000.00
Hora impresión 3D | CLAB | 50 | $ 10,000.00 | $ 500,000.00
Hora laboratorio electrónica | CLAB | 50 | $ 5,000.00 | $ 250,000.00
| | | Total: | $ 7,985,000.00

# Propiedad Intelectual

Según el reglamento de propiedad intelectual de la universidad [5], este proyecto pertenece a la categoría de propiedad industrial, cuyos derechos serán atribuidos al inventor Sebastián Jiménez Henao, y a los inversores, en este caso el CLAB, dado la inversión detallada en el apartado de presupuesto. Los detalles de los derechos de explotación del diseño serán determinados en las etapas finales del proyecto, en acuerdo con los directivos pertinentes del CLAB.

# Bibliografía

[1] | PHYWE Systeme GmbH & Co., "Dielectric constant of different materials," Göttingen.
[2] | PHYWE Systeme GmbH & Co., "Diffraction through a slit and Heisenberg's uncertainty principle," Göttingen.
[3] | PHYWE Systeme GmbH & Co., "Plank's "quantum of action" from the photoelectric effect (line separation by difraction)," Göttingen.
[4] | PHYWE Systeme GmbH & Co., "Universal Amplifier Operating Instructions," Göttingen.
[5] | Universidad EAFIT, «Reglamento de Propiedad Intelectual,» Editorial EAFIT, Medellín, 2018.
[6] | SnapEDA Team, "The Top 10 Operational Amplifiers on SnapEDA," 23 October 2019. [Online]. Available: https://blog.snapeda.com/2019/10/23/the-top-10-operational-amplifiers/.
[7] | Texas Instruments, Op Amps for Everyone, Dallas: Texas Instruments Incorporated, 2002.

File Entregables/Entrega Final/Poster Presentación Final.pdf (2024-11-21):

# Desarrollo de Voltímetro de Instrumentación y Electrómetro de Instrumentación para su Uso en Laboratorios de Física

S. Jiménez* y C. A. Trujillo† Escuela de Ciencias Aplicadas e Ingeniería, Universidad EAFIT. Carrera 49 #7 sur 50, Medellín, Colombia. *sjimenezh1@eafit.edu.co
†catrujilla@eafit.edu.co

RESUMEN. Se desarrollaron un voltímetro y un electrómetro de instrumentación como alternativas económicas al amplificador universal de PHYWE, destinados a laboratorios de física. El voltímetro fue validado con éxito en experimentos que confirman el Principio de Incertidumbre de Heisenberg, mientras que el electrómetro, optimizado para la determinación de la constante de Planck y constantes dieléctricas, está en su etapa final de fabricación y validación. Ambos instrumentos priorizan modularidad, reparabilidad y adecuación educativa, ofreciendo soluciones compactas, funcionales y asequibles para experimentos de física moderna y electromagnetismo.


AGRADECIMIENTOS Agradecemos a Carlos Alejandro Trujillo, Álvaro Andrés Velásquez, y al Centro de Laboratorios de EAFIT por su apoyo técnico y financiero en el desarrollo de este proyecto.

INTRODUCCIÓN El acceso a instrumentos de medición precisos y asequibles es fundamental para la enseñanza de la física experimental. Este proyecto aborda las limitaciones del amplificador universal de PHYWE, como su alto costo y complejidad, mediante el desarrollo de un voltímetro y un electrómetro de instrumentación diseñados específicamente para laboratorios educativos. Estos dispositivos son compactos, reparables y optimizados para experimentos clave como la confirmación del Principio de Incertidumbre de Heisenberg y la determinación de la constante de Planck, ofreciendo una solución práctica y sostenible para mejorar la experiencia educativa en física moderna

FUNDAMENTOS Los instrumentos desarrollados están diseñados para ser utilizados en dos experimentos clave de física moderna:

### 1. Confirmación del Principio de Incertidumbre de

Heisenberg: Este experimento utiliza un láser He-Ne que atraviesa una rendija simple, generando un patrón de difracción. El voltímetro mide los voltajes generados por una fotocélula al capturar la luz difractada en puntos clave, como el máximo central y el primer mínimo, permitiendo calcular los ángulos de difracción y validar la relación de incertidumbre.

### 2. Determinación de la Constante de Planck: En este

experimento, una lámpara de vapor de mercurio emite un espectro que es difractado mediante una rejilla de 600 líneas/mm. La luz seleccionada incide sobre una fotocélula de vacío, generando un voltaje proporcional a la frecuencia de la luz. El electrómetro mide estos voltajes, permitiendo calcular la constante de Planck a partir de la relación lineal entre energía y frecuencia de la luz incidente.

METODOLOGÍA El desarrollo siguió un proceso iterativo dividido en etapas: diseño electrónico, fabricación de carcasas, ensamblaje y pruebas funcionales. Se realizaron tres prototipos del voltímetro y dos del electrómetro, refinando aspectos como la disposición de los componentes, modularidad y reparabilidad. Las carcasas fueron diseñadas en Autodesk Fusion 360 e impresas en PETG utilizando una Creality CR-10 modificada. Este enfoque permitió ajustar y optimizar los instrumentos para cumplir con los requisitos específicos de los experimentos de física moderna.

RESULTADOS Y ANÁLISIS Los instrumentos desarrollados fueron evaluados en dos aplicaciones principales de física moderna, mostrando resultados alineados con los objetivos del proyecto:
Voltímetro: Validado en el experimento de confirmación del Principio de Incertidumbre de Heisenberg, el voltímetro midió los voltajes generados por una fotocélula en puntos clave del patrón de difracción. Se registró una relación experimental de 2.0038 en lugar de 1, atribuida a un error en la guía de laboratorio y no al desempeño del instrumento. El voltímetro alcanzó una precisión de ±1 mV, equivalente al amplificador PHYWE en su modo de baja deriva.

### CONCLUSIONES

El voltímetro y el electrómetro desarrollados ofrecen alternativas asequibles y funcionales al amplificador universal PHYWE para laboratorios de física. El voltímetro fue validado en el experimento del Principio de Incertidumbre de Heisenberg, mostrando precisión equivalente y un diseño compacto. El electrómetro, optimizado para medir la constante de Planck y constantes dieléctricas, se encuentra en etapa final de ajustes. Ambos instrumentos destacan por su modularidad y adecuación educativa, mejorando la accesibilidad y funcionalidad en contextos experimentales.

Característica | Voltímetro/Electró metro | Amplificador PHYWE
Resolución (Voltímetro) | ±1 mV | ±1 mV
Resolución (Electrómetro) | ±1 mV | ±10 mV
Impedancia (Electrómetro) | 10^12 Ω | 10^13 Ω
Rango de voltaje (Electrómetro) | 0-5 V | ±10 V

GITHUB Contiene referencias, archivos de diseño CAD, modelos listos para imprimir, documentación pertinente, proyecto en KiCad, y mucho más ¡Dale una mirada!

Tabla 1: Comparativa entre los instrumentos desarrollados y el amplificador de medición universal PHYWE.

Electrómetro: Diseñado para medir voltajes en experimentos como la determinación de la constante de Planck y constantes dieléctricas, el electrómetro presenta una alta resistencia de entrada (10^12 Ω) y un rango de 0-5 V, suficiente para los voltajes esperados en estos experimentos. Aunque el diseño inicial presentó un fallo debido a un corto en la fuente de alimentación, las iteraciones finales incorporaron mejoras en reparabilidad y durabilidad.

Figura 1: Iteraciones previas (a) Primer prototipo (b) Segundo prototipo

(a) (b)

Comparativa con el Amplificador PHYWE: Ambos instrumentos cumplen o exceden con los requisitos experimentales, destacándose por su diseño compacto y duradero. En el modo electrométrico, el electrómetro supera la resolución del PHYWE, que está limitado a ±10 mV.

Figura 2: Voltímetro (a) Desempeño en las condiciones de medición (b) Integración con aparato experimental de confirmación del principio de incertidumbre de Heisenberg

(a) (b)
Figura 3: Detalle del voltímetro final (4to prototipo). | Figura 4: Integración del Electrómetro al experimento de determinación de la constante de Planck

Figura 3: Detalle del amplificador de medición universal fabricado por PHYWE

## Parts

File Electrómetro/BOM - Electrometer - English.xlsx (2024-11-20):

Part | Quantity | Description
M3x10mm | 9 | Button Head, to secure legs and enclosure
M3 washer | 9 | To prevent static flow of plastic at attachment points
M2x5mm | 4 | Button Head, to secure mainboard
M3 nut | 6 | To secure C13 socket and legs
M3 threaded insert | 5 | OD 6mm, 5mm length, 3D print type
M2 threaded insert | 4 | OD 3.5mm, 3mm length, 3D print type
Perfboard 4cmx6cm | 1 | For Mainboard
YB5145B | 1 | Voltmeter w/ Display. 24V supply, +-20V input range
HW-613 | 1 | Mini DC-DC converter, configured to 5V fixed output
10k Ohm Resistor | 1 | Safety discharge resistor
5k Ohm resistor | 1 | Noninverting input undervoltage protection
DS-428 | 1 | Panel mount microswitch w/button
YS-12V450A | 1 | Mini AC-DC power supply, 24V
C13 Socket | 1 | With fuse and switch, screw mounted
AWG 22 x1 m | 1 | For traces in the mainboard
Screw terminal block 2x | 5 | For easy part swaps
Tapa | 1 | PETG or ABS recommended, see print settings
Cuerpo | 1 | PETG or ABS recommended, see print settings
Pata | 4 | TPU recommended, see print settings
DIP-8 Socket | 1 | For easy part swaps

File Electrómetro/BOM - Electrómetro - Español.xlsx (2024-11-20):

Parte | Cantidad | Descripción
M3x10mm | 9 | Cabeza de botón, para asegurar las patas y el cerramiento
Arandela M3 | 9 | Para evitar el flujo estático de plástico en los puntos de fijación
M2x5mm | 4 | Cabeza de botón, para asegurar la placa base
Tuerca M3 | 6 | Para asegurar el socket C13 y las patas
Inserto roscado M3 | 5 | OD 6 mm, 5 mm de longitud, tipo de impresión 3D
Inserto roscado M2 | 4 | OD 3,5 mm, 3 mm de longitud, tipo de impresión 3D
Perfboard 4cmx6cm | 1 | Para placa base
YB5145B | 1 | Voltímetro con pantalla. Alimentación de 24 V, rango de entrada de +-20 V
HW-613 | 1 | Mini convertidor DC-DC, configurado para salida fija de 5V
Resistencia de 10k ohmios | 1 | Resistencia de descarga de seguridad
Resistencia de 5k Ohm | 1 | Protección contra subtensión de entrada no inversora
DS-428 | 1 | Microinterruptor de montaje en panel con botón
YS-12V450A | 1 | Mini fuente de alimentación CA-CC, 24 V
Socket C13 | 1 | Con fusible e interruptor, montaje con tornillos
AWG 22 x1 m | 1 | Para trazas en la placa base
Bloque de terminales de tornillo 2x | 5 | Para facilitar el intercambio de piezas
Tapa | 1 | Se recomienda PETG o ABS, consulte la configuración de impresión
Cuerpo | 1 | Se recomienda PETG o ABS, consulte la configuración de impresión
Pata | 4 | Se recomienda TPU, consulte la configuración de impresión
Socket DIP-8 | 1 | Para facilitar el intercambio de piezas

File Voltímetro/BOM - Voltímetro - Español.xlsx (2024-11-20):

Parte | Cantidad | Descripción
M3x10mm | 9 | Cabeza de botón, para asegurar las patas y la carcasa
Arandela M3 | 9 | Para evitar el flujo estático de plástico en los puntos de fijación
M2x5mm | 4 | Cabeza de botón, para asegurar la placa base
Tuerca M3 | 6 | Para asegurar el socket C13 y las patas
Inserto roscado M3 | 5 | OD 6 mm, 5 mm de longitud, tipo de impresión 3D
Inserto roscado M2 | 4 | OD 3,5 mm, 3 mm de longitud, tipo de impresión 3D
Perfboard 4cmx6cm | 1 | Para placa base
YB5145B | 1 | Voltímetro con pantalla. Alimentación de 24 V, rango de entrada de +-20 V
YS-12V450A | 1 | Mini fuente de alimentación CA-CC, 24 V
Zócalo C13 | 1 | Con fusible e interruptor, atornillado
AWG 22 x1M | 1 | Para trazas en la placa base
Zócalo C13 | 1 | Con fusible e interruptor, montaje con tornillos
Bloque de terminales de tornillo 2x | 4 | Para facilitar el intercambio de piezas
Tapa | 1 | Se recomienda PETG o ABS, consulte la configuración de impresión
Cuerpo | 1 | Se recomienda PETG o ABS, consulte la configuración de impresión
Pata | 4 | Se recomienda TPU, consulte la configuración de impresión

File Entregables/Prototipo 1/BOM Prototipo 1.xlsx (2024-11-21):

Parte | Cantidad | Precio | Link | Total:
[D69-30] Voltímetro con pantalla digital | 1 | $32400.13 | Voltímetro con pantalla digital. 0-600VDC | Didácticas Electrónicas I+D (didacticaselectronicas.com.co) (https://www.didacticaselectronicas.com.co/en/shop/d69-30-600vdc-voltimetro-con-pantalla-digital-0-600vdc-33621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) | $147205.38
[PWR-110-12V-300MA] Fuente AC-DC 12V/300mA | 1 | $7800.45 | Fuente AC-DC 12V/300mA | Didácticas Electrónicas I+D (didacticaselectronicas.com.co) (https://www.didacticaselectronicas.com.co/en/shop/pwr-110-12v-300ma-fuente-ac-dc-12v-300ma-15426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)
Filamento PETG | 1 | $86000.11 | Filamento Plata PETG para impresora 3D, 1.75mm | Didácticas Electrónicas I+D (didacticaselectronicas.com.co) (https://www.didacticaselectronicas.com.co/en/shop/petg-1k-plata-filamento-plata-petg-para-impresora-3d-1-75mm-23372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)
[TB2PB-5R] Bornera 2P Roja KF301 - 5mm | 2 | $599.76 | Bornera 2P Roja KF301 - 5mm | Didácticas Electrónicas I+D (didacticaselectronicas.com.co) (https://www.didacticaselectronicas.com.co/en/shop/tb2pb-5r-bornera-2p-roja-kf301-5mm-24466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)
[AC09] Conector 250VAC/15A, con suiche, para Panel | 1 | $9399.81 | Conector 250VAC/15A, con suiche, para Panel | Didácticas Electrónicas I+D (didacticaselectronicas.com.co) (https://www.didacticaselectronicas.com.co/en/shop/ac09-conector-250vac-15a-con-suiche-para-panel-8795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)
[CON-035A] Conector para chasis BNC hembra con tuerca | 1 | $2303.84 | Conector para chasis BNC hembra con tuerca | Didácticas Electrónicas I+D (didacticaselectronicas.com.co) (https://www.didacticaselectronicas.com.co/en/shop/con-035a-conector-para-chasis-bnc-hembra-con-tuerca-19202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)
[CA-PODER] Cable de Poder Redondo 1.5m | 1 | $6479.55 | Cable de Poder Redondo 1.5m | Didácticas Electrónicas I+D (didacticaselectronicas.com.co) (https://www.didacticaselectronicas.com.co/en/shop/ca-poder-cable-de-poder-redondo-1-5m-20660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)
[PROTOTYPE-2] Circuito impreso universal 4x6cm | 1 | $1621.97 | Circuito impreso universal 4x6cm | Didácticas Electrónicas I+D (didacticaselectronicas.com.co) (https://www.didacticaselectronicas.com.co/en/shop/prototype-2-circuito-impreso-universal-4x6cm-2729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)

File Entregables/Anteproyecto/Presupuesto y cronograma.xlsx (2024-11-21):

Ítem | Encargado | Cantidad | Precio por unidad | Subtotal | Etapa | Diseño electrónica | Diseño Carcasa | Elaboración electrónica | Elaboración carcasa | Pruebas de funcionamiento
Hora consultoría: Carlos Trujillo | CLAB | 10 | $100000.00 | $1000000.00 | Prototipo 1 | Semana 4 | Semana 4 | Semana 5 | Semana 5 | Semana 6
Hora consultoría: Álvaro Velásquez | CLAB | 5 | $100000.00 | $500000.00 | Prototipo 2 | Semana 6 | Semana 7 | Semana 7 | Semana 7 | Semana 8
Hora de trabajo: Sebastián Jiménez | CLAB | 100 | $50000.00 | $5000000.00 | Amplificador final | Semana 8 | Semana 9 | Semana 9 | Semana 10 | Semana 10
Filamento PETG 1 kg | CLAB | 2 | $98000.00 | $196000.00
Set tornillería | CLAB | 3 | $10000.00 | $30000.00
Módulo voltímetro 7 segmentos | CLAB | 3 | $30000.00 | $90000.00
Fuente 12V | CLAB | 3 | $10000.00 | $30000.00
Op-Amp LM324 | CLAB | 5 | $1600.00 | $8000.00
Selector rotativo | CLAB | 3 | $22000.00 | $66000.00
Electrónica - varios | CLAB | 1 | $300000.00 | $300000.00
Conector BNC | CLAB | 5 | $3000.00 | $15000.00
Hora impresión 3D | CLAB | 50 | $10000.00 | $500000.00
Hora laboratorio electrónica | CLAB | 50 | $5000.00 | $250000.00
 |  |  | Total: | $7985000.00

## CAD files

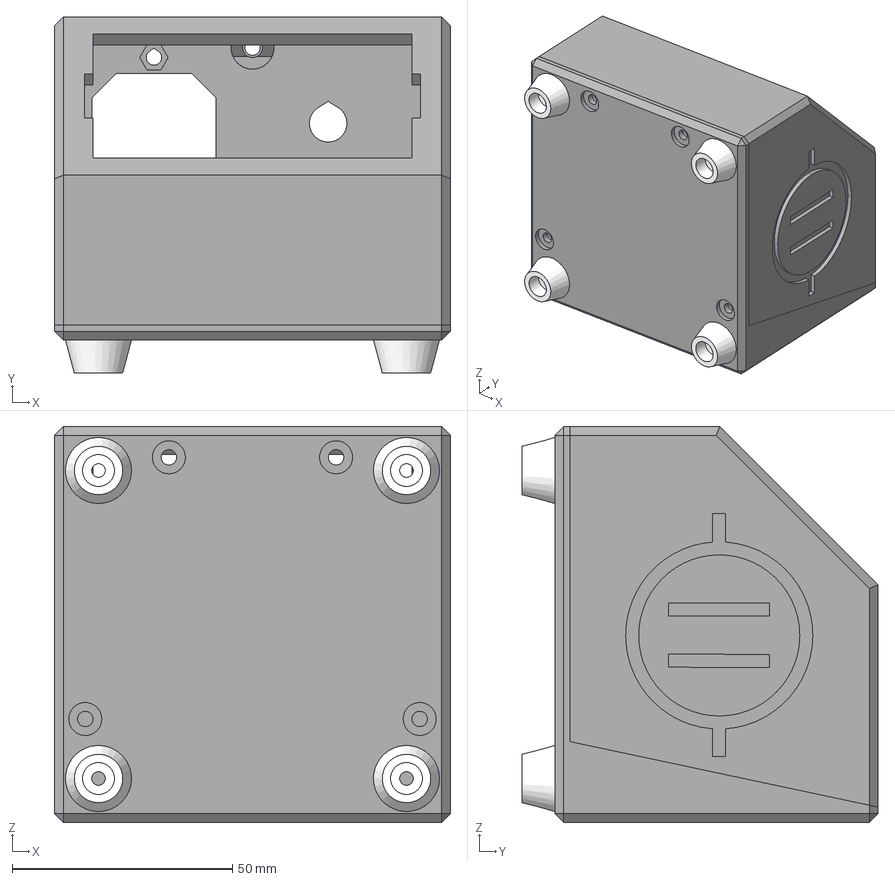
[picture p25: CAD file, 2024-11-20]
Electrómetro/CAD/Electrómetro v4.step
90.0 x 81.0 x 90.0 mm

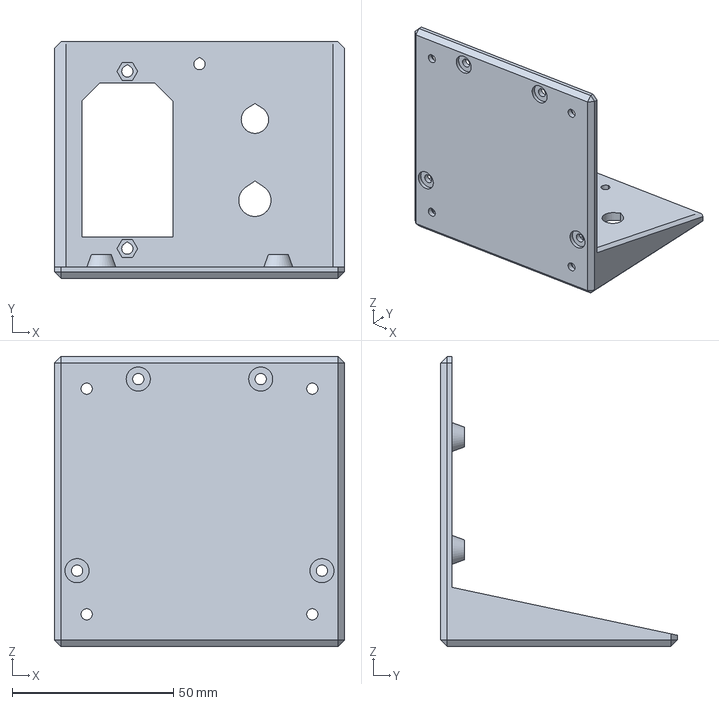
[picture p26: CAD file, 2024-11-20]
Electrómetro/STL/Cuerpo.3mf
90.0 x 73.5 x 90.0 mm

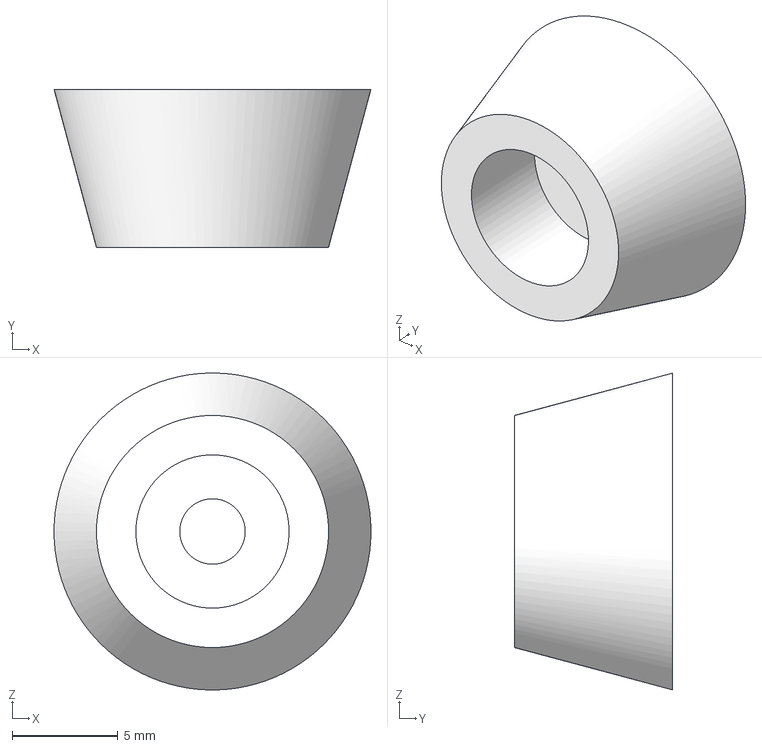
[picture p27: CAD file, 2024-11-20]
Voltímetro/STL/Pata.3mf
15.0 x 7.50 x 15.0 mm

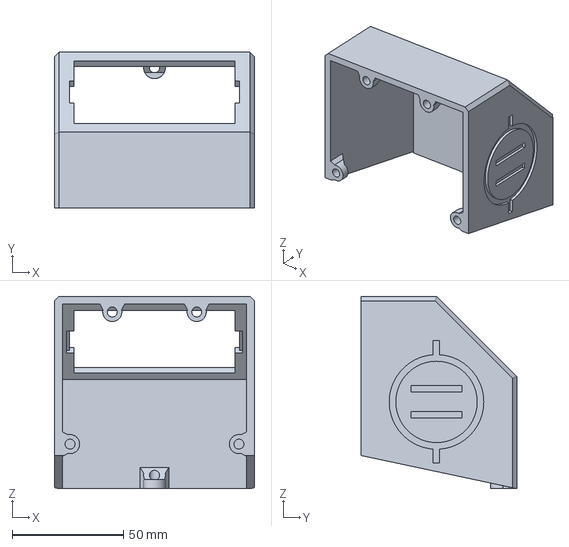
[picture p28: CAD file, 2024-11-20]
Electrómetro/STL/Tapa.3mf
90.0 x 70.0 x 86.5 mm

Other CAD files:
Voltímetro/CAD/Voltímetro v10.step
Voltímetro/STL/Tapa.3mf
Voltímetro/STL/Cuerpo.3mf
Electrómetro/CAD/Electrómetro v4.f3d
Voltímetro/CAD/Voltímetro v10.f3d

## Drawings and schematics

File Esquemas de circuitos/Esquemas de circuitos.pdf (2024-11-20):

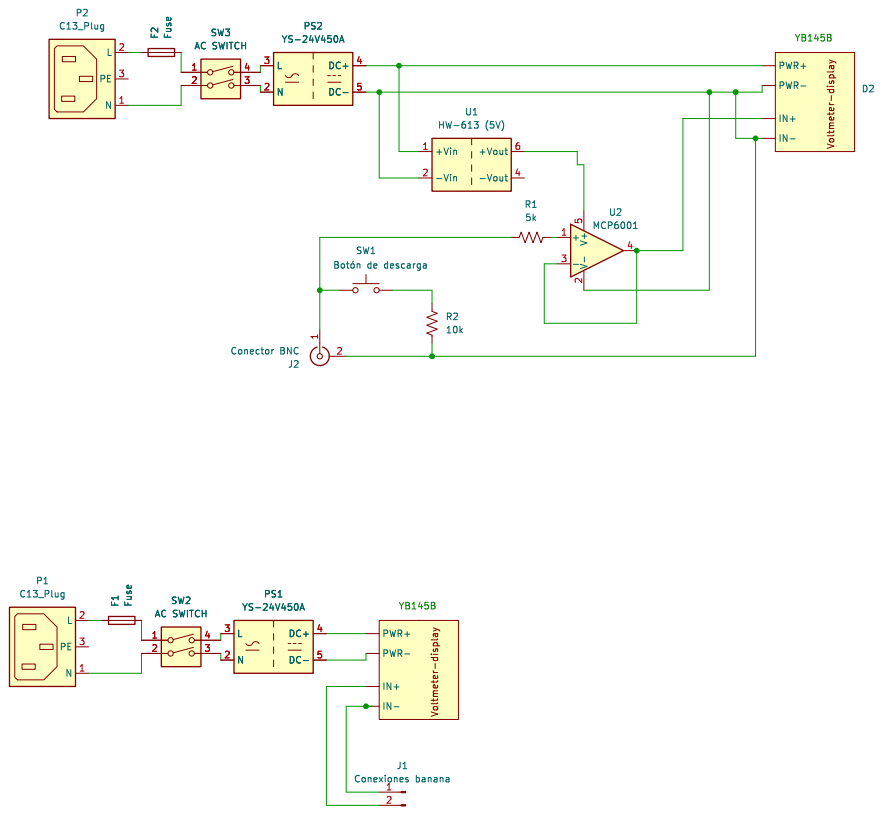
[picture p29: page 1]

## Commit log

2024-11-20 Main upload
    [BOM - Electrometer - English.xlsx, BOM - Electrómetro - Español.xlsx, BOM - Voltmeter - Engllish.xlsx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]
2024-11-20 References and circuit diagrams
    [Esquemas de circuitos.kicad_pcb, Esquemas de circuitos.kicad_sch]
2024-11-21 Documentation upload
    [BOM Prototipo 1.xlsx, Presupuesto y cronograma.xlsx]
